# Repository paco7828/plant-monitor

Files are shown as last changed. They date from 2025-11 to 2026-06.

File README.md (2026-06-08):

# Plant Monitor

An ESP32-based smart plant monitoring system with automatic watering, Home Assistant integration via MQTT, and deep sleep power management. Consists of two independent units: the **Plant Monitor** (sensor node) and the **Watering Station** (pump actuator).

---

## System Overview

```
[Plant Monitor ESP32]  --MQTT-->  [MQTT Broker]  --MQTT-->  [Watering Station ESP32]
        |                              |
   Reads sensors                Home Assistant
   Triggers watering cmd         Dashboard / Automations
```

The plant monitor reads sensors and publishes data. When soil moisture drops below the threshold it sends a watering command over MQTT. The watering station subscribes to that command and activates the pump. Both units connect independently to the same WiFi network and MQTT broker.

---

## Hardware

### Plant Monitor

| Component | GPIO |
|---|---|
| Soil moisture sensor (analog) | 0 |
| DS18B20 temperature sensor (OneWire) | 1 |
| LDR light sensor (analog) | 2 |
| Buzzer | 3 |

- ESP32 with deep sleep support
- DS18B20 requires a 4.7k pull-up resistor on the data line

### Watering Station

| Component | GPIO |
|---|---|
| Pump relay / MOSFET | 0 |
| Manual trigger button | 1 |

- Separate ESP32 unit
- Button is active LOW (internal pull-up enabled)
- Manual button press activates the pump for the configured duration regardless of MQTT

---

## Features

### Plant Monitor

**Sensors**
- Soil moisture (analog ADC)
- Ambient temperature via DS18B20 (Dallas OneWire)
- Light presence detection (LDR with configurable threshold)

**Power Management**
- Deep sleep during dark periods (night), waking every 30 minutes to check and publish sensor data
- Stays awake during daylight and publishes every 60 seconds
- RTC memory (`RTC_DATA_ATTR`) persists boot count, sleep time accumulation, last watering time, and last low-moisture beep time across sleep cycles

**Automation**
- Automatic watering triggered when moisture falls below threshold (`MOISTURE_THRESHOLD = 2900`)
- 5-minute cooldown between watering cycles, tracked across deep sleep via RTC memory
- Low moisture buzzer alert every 5 minutes when soil is dry, also tracked across sleep

**Configuration Portal**
- On cold boot: opens WiFi AP (`Smart-Pot`, no password) for 3 minutes
- Captive portal at `192.168.4.1` for entering WiFi SSID/password and MQTT broker settings
- Settings persisted to NVS (`Preferences`)
- On subsequent wakeups from sleep: connects directly using saved credentials

### Watering Station

- Subscribes to `smartpot/water_command`; activates pump for 5 seconds on receiving `"1"`
- Manual button override: activates pump for 5 seconds regardless of MQTT state
- Same captive portal setup flow as the plant monitor for WiFi + MQTT configuration
- WiFi state machine with automatic retry every 15 seconds on connection failure

---

## MQTT Topics

| Topic | Direction | Description |
|---|---|---|
| `smartpot/temperature` | Publish | Temperature in degrees C (string, 2 decimal places) |
| `smartpot/soil_moisture` | Publish | Raw ADC value from moisture sensor |
| `smartpot/sunlight_presence` | Publish | `1` = light, `0` = dark |
| `smartpot/last_watering_time` | Publish (retained) | ISO timestamp of last watering event |
| `smartpot/water_command` | Publish / Subscribe | Plant monitor sends `"1"` to trigger watering |

---

## WiFi / MQTT Configuration

Both units use the same captive portal flow:

1. Power on (cold boot)
2. Connect to the AP (`Smart-Pot` or `Watering-station`)
3. Browser opens the configuration page automatically (captive portal) or navigate to `192.168.4.1`
4. Fill in WiFi credentials and MQTT broker details
5. Submit - the unit connects and begins operation

Configuration is saved to NVS and survives reboot and deep sleep.

---

## Deep Sleep Behavior (Plant Monitor)

| Condition | Behavior |
|---|---|
| Cold boot | AP mode for configuration, then normal operation |
| Dark (LDR below threshold) | Sleep 30 minutes, wake, send data, sleep again |
| Light (LDR above threshold) | Stay awake, send data every 60 seconds |
| MQTT connected + data sent + 15 s minimum awake | Eligible to sleep (if dark) |

Timers that must survive sleep are accumulated in `rtcData.totalSleepTime` so that intervals like watering cooldown and beep suppression work correctly across wakeup cycles.

---

## Thresholds and Timing

### Plant Monitor

| Parameter | Value |
|---|---|
| Moisture threshold (dry) | 2900 (ADC raw) |
| Sunlight threshold | 1500 (ADC raw) |
| Watering cooldown | 5 minutes |
| Low moisture beep interval | 5 minutes |
| Day publish interval | 60 seconds |
| Night sleep interval | 30 minutes |
| AP timeout (cold boot) | 3 minutes |
| WiFi retry interval | 15 seconds |

### Watering Station

| Parameter | Value |
|---|---|
| Pump on duration | 5 seconds |
| AP timeout | 2 minutes |
| WiFi retry interval | 15 seconds |
| Status log interval | 10 seconds |

---

## Home Assistant Integration

Add the following to `configuration.yaml` to expose all entities:

```yaml
mqtt:
  sensor:
    - name: "Smart Pot Temperature"
      state_topic: "smartpot/temperature"
      unit_of_measurement: "C"
      device_class: temperature

    - name: "Smart Pot Soil Moisture"
      state_topic: "smartpot/soil_moisture"

    - name: "Smart Pot Last Watering"
      state_topic: "smartpot/last_watering_time"

  binary_sensor:
    - name: "Smart Pot Sunlight"
      state_topic: "smartpot/sunlight_presence"
      payload_on: "1"
      payload_off: "0"
      device_class: light
```

Restart Home Assistant after editing `configuration.yaml`.

---

## Dependencies

### Plant Monitor

- `OneWire`
- `DallasTemperature`
- `PubSubClient`
- `WiFi`, `WebServer`, `DNSServer`, `Preferences`, `esp_sleep` (built-in ESP32 Arduino)

### Watering Station

- `PubSubClient`
- `WiFi`, `WebServer`, `DNSServer`, `Preferences` (built-in ESP32 Arduino)

---

## Notes

- Both units use `configTime(3600, 3600, "pool.ntp.org")` for NTP time, providing CET offset with DST — adjust the second argument to `0` outside DST periods or use a proper POSIX timezone string for automatic DST handling
- The DS18B20 returns `DEVICE_DISCONNECTED_C` on failure; this is checked before publishing to avoid sending garbage temperature values
- Watering station button is debounced implicitly by the `pumpActive` flag preventing re-trigger while the pump is running

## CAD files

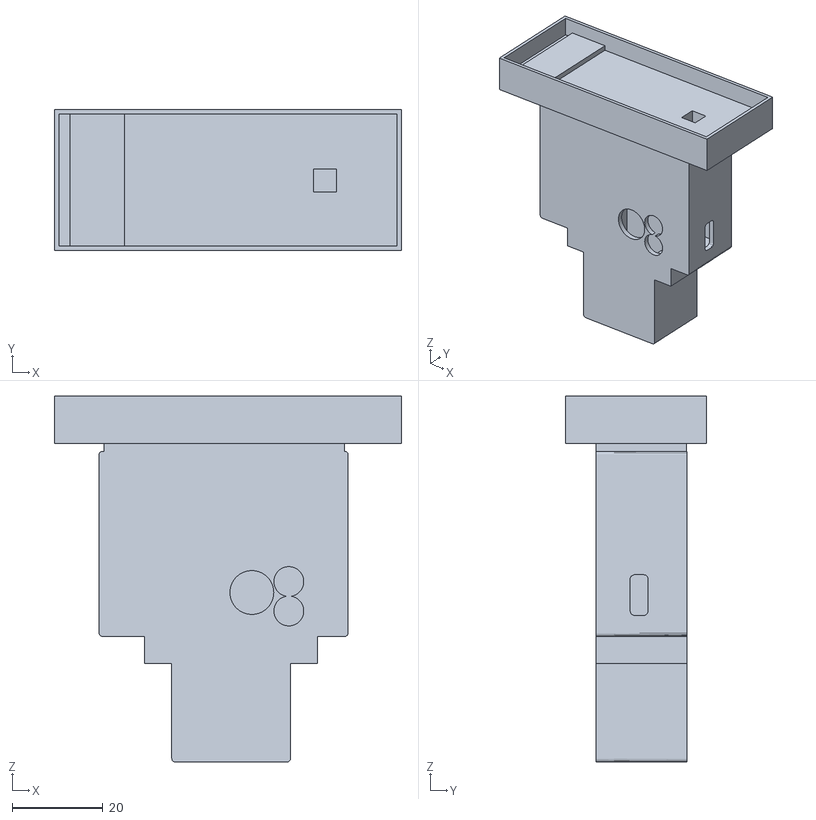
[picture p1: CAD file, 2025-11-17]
v4/Plant-monitor.stl
76.5 x 31.0 x 80.6

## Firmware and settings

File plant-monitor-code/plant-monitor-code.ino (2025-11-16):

#include "config.h"
#include "wifi-handler.h"
#include <OneWire.h>
#include <DallasTemperature.h>
#include <esp_sleep.h>

// Instances
OneWire oneWire(DS_TEMP_PIN);
DallasTemperature temperatureSensor(&oneWire);
WifiHandler wifiHandler;

// Function prototypes
void handleSensorOperations(unsigned long currentMillis);
void handleBuzzerAlerts(unsigned long currentMillis);
void handleAutomation(unsigned long currentMillis);
void handleAPMode(unsigned long currentMillis);
void handleWiFiStateMachine(unsigned long currentMillis);
void goToDeepSleep();
bool areAllTasksCompleted();

void setup() {
  Serial.begin(115200);

  // Pin modes
  pinMode(LDR_PIN, INPUT);
  pinMode(MOISTURE_PIN, INPUT);
  pinMode(BUZZER_PIN, OUTPUT);

  // Check if this is a cold boot
  esp_sleep_wakeup_cause_t wakeup_reason = esp_sleep_get_wakeup_cause();
  isColdBoot = (wakeup_reason == ESP_SLEEP_WAKEUP_UNDEFINED);

  // Play startup sound only on cold boot
  if (isColdBoot) {
    Serial.println("Cold boot detected");
    for (int i = 0; i < 3; i++) {
      tone(BUZZER_PIN, MELODY[i], DURATIONS[i]);
      delay(DELAYS[i]);
    }
  } else {
    Serial.println("Waking from deep sleep");
  }

  temperatureSensor.begin();

  // Initialize or update RTC data
  if (!rtcData.isInitialized) {
    rtcData = { true, 0, 0, 0, 0 };  // Aggregate initialization
  } else {
    rtcData.bootCount++;
    if (rtcData.bootCount > 1) {
      rtcData.totalSleepTime += (DARK_SEND_INTERVAL / 1000);
    }
  }

  // Initialize state variables
  wakeupTime = millis();
  tasksCompleted = false;
  justWokeUp = true;

  // Load configuration
  bool hasCredentials = wifiHandler.loadWiFiCredentials();
  wifiHandler.loadMQTTConfig();

  // Determine initial WiFi state based on boot type and credentials
  if (isColdBoot) {
    // Cold boot - start AP mode first
    Serial.println("Cold boot: Starting Access Point for configuration...");
    wifiHandler.startAccessPoint();
    currentWiFiState = WIFI_SETUP_MODE;
  } else if (hasCredentials) {
    // On wake from sleep with credentials, connect directly
    Serial.println("Wake from sleep: Attempting direct WiFi connection...");
    WiFi.mode(WIFI_STA);
    currentWiFiState = WIFI_CONNECTING;
  } else {
    // Wake from sleep without credentials - start AP
    Serial.println("Wake from sleep: No credentials, starting AP...");
    wifiHandler.startAccessPoint();
    currentWiFiState = WIFI_SETUP_MODE;
  }
}

void loop() {
  unsigned long currentMillis = millis();

  // Handle AP mode if active
  if (wifiHandler.isApModeActive()) {
    handleAPMode(currentMillis);
  }

  // State-independent operations
  isWatering = false;
  handleBuzzerAlerts(currentMillis);

  // WiFi state machine
  handleWiFiStateMachine(currentMillis);

  // Check for deep sleep conditions
  if (!wifiHandler.isApModeActive() && areAllTasksCompleted()) {
    goToDeepSleep();
  }

  delay(100);
}

void handleAPMode(unsigned long currentMillis) {
  wifiHandler.dnsServer.processNextRequest();
  wifiHandler.server.handleClient();

  // Check for AP timeout (only on cold boot)
  if (isColdBoot && (currentMillis - wifiHandler.getApStartTime() >= AP_TIMEOUT)) {
    wifiHandler.stopAccessPoint();
    Serial.println("AP timeout reached on cold boot, stopping AP");

    // Attempt WiFi connection if credentials exist
    if (wifiHandler.loadWiFiCredentials()) {
      WiFi.mode(WIFI_STA);
      currentWiFiState = WIFI_CONNECTING;
      Serial.println("Credentials available, attempting WiFi connection...");
    } else {
      currentWiFiState = WIFI_FAILED;
      Serial.println("No credentials available, operations limited until configured");
    }

    // Clear cold boot flag after first AP timeout
    isColdBoot = false;
  }

  // Handle new credentials saved during AP mode
  if (wifiHandler.areCredentialsSaved()) {
    wifiHandler.setCredentialsSaved(false);
    Serial.println("New credentials saved, stopping AP and attempting connection...");

    // Small delay to allow the HTTP response to be sent
    delay(100);

    wifiHandler.stopAccessPoint();
    delay(1000);
    WiFi.mode(WIFI_STA);
    currentWiFiState = WIFI_CONNECTING;
    isColdBoot = false;  // Clear cold boot flag after successful config
  }
}

void handleWiFiStateMachine(unsigned long currentMillis) {
  switch (currentWiFiState) {
    case WIFI_SETUP_MODE:
      // Waiting in AP mode - nothing to do
      break;

    case WIFI_CONNECTING:
      if (wifiHandler.connectWiFi()) {
        currentWiFiState = WIFI_CONNECTED;
        Serial.println("WiFi connected successfully!");
      } else {
        currentWiFiState = WIFI_FAILED;
        lastWiFiAttempt = currentMillis;
        Serial.println("WiFi connection failed");
      }
      break;

    case WIFI_CONNECTED:
      // Check if WiFi connection is still alive
      if (WiFi.status() != WL_CONNECTED) {
        currentWiFiState = WIFI_FAILED;
        lastWiFiAttempt = currentMillis;
        Serial.println("WiFi connection lost");
        break;
      }

      // Ensure MQTT connection
      if (!wifiHandler.client.connected()) {
        Serial.println("Connecting to MQTT...");
        wifiHandler.reconnectMQTT();
      }

      // Process MQTT and sensor operations if connected
      if (wifiHandler.client.connected()) {
        wifiHandler.client.loop();
        handleSensorOperations(currentMillis);
        handleAutomation(currentMillis);
      }
      break;

    case WIFI_FAILED:
      // Retry WiFi connection after interval
      if (currentMillis - lastWiFiAttempt >= WIFI_RETRY_INTERVAL) {
        currentWiFiState = WIFI_CONNECTING;
        Serial.println("Retrying WiFi connection...");
      }
      break;
  }
}

void handleSensorOperations(unsigned long currentMillis) {
  ldrValue = analogRead(LDR_PIN);
  isDark = ldrValue <= SUNLIGHT_THRESHOLD;

  bool shouldSendData = justWokeUp || (!isDark && (currentMillis - lastDataSendTime >= LIGHT_SEND_INTERVAL));

  if (shouldSendData) {
    lastDataSendTime = currentMillis;
    justWokeUp = false;

    // Read sensors
    temperatureSensor.requestTemperatures();
    temperature = temperatureSensor.getTempCByIndex(0);
    moisture = analogRead(MOISTURE_PIN);

    char dataBuffer[10];

    // Send temperature if valid
    if (temperature != DEVICE_DISCONNECTED_C && temperature > -55 && temperature < 125) {
      dtostrf(temperature, 1, 2, dataBuffer);
      wifiHandler.sendTemperature(dataBuffer);
    }

    // Send moisture
    itoa(moisture, dataBuffer, 10);
    wifiHandler.sendMoisture(dataBuffer);

    // Send sunlight presence
    dataBuffer[0] = isDark ? '0' : '1';
    dataBuffer[1] = '\0';
    wifiHandler.sendSunlightPresence(dataBuffer);

    delay(1000);
  }
}

bool areAllTasksCompleted() {
  unsigned long currentMillis = millis();

  // Minimum awake time requirement
  if (currentMillis - wakeupTime < 15000) {
    return false;
  }

  // Must be dark, data sent after wakeup, and MQTT connected
  if (!isDark || lastDataSendTime <= wakeupTime || !wifiHandler.client.connected()) {
    return false;
  }

  // Track MQTT connection time for watering opportunity
  static unsigned long mqttConnectedTime = 0;

  if (mqttConnectedTime == 0) {
    mqttConnectedTime = currentMillis;
  }

  // Give at least 10 seconds after MQTT connection for watering decision
  if (currentMillis - mqttConnectedTime < 10000) {
    return false;
  }

  return true;
}

void handleBuzzerAlerts(unsigned long currentMillis) {
  // Periodic moisture reading
  if (currentMillis - lastMoistureReading >= 5000) {
    moisture = analogRead(MOISTURE_PIN);
    lastMoistureReading = currentMillis;
  }

  // Calculate time since last beep including sleep time
  unsigned long timeSinceLastBeep = rtcData.totalSleepTime + currentMillis - rtcData.lastLowMoistureBeep;

  // Trigger low moisture beep if needed
  if (moisture < MOISTURE_THRESHOLD && timeSinceLastBeep >= LOW_MOISTURE_BEEP_INTERVAL) {
    tone(BUZZER_PIN, LOW_MOISTURE_HZ, 200);
    rtcData.lastLowMoistureBeep = rtcData.totalSleepTime + currentMillis;
    Serial.println("Low moisture beep triggered");
  }
}

void handleAutomation(unsigned long currentMillis) {
  // Only operate when MQTT is connected
  if (!wifiHandler.client.connected()) {
    return;
  }

  // Periodic moisture check and watering decision
  static unsigned long lastMoistureCheck = 0;

  if (currentMillis - lastMoistureCheck >= 2000) {
    lastMoistureCheck = currentMillis;
    moisture = analogRead(MOISTURE_PIN);
    lastMoistureReading = currentMillis;

    Serial.print("Automation - Moisture: ");
    Serial.print(moisture);
    Serial.print(" | Threshold: ");
    Serial.print(MOISTURE_THRESHOLD);
    Serial.print(" | Dry: ");
    Serial.println(moisture < MOISTURE_THRESHOLD ? "YES" : "NO");

    // Check if watering is needed
    if (moisture < MOISTURE_THRESHOLD) {
      unsigned long timeSinceLastWatering = rtcData.totalSleepTime + millis() - rtcData.lastWateringTime;

      if (timeSinceLastWatering >= WATERING_COOLDOWN) {
        // Trigger watering sequence
        wifiHandler.sendWaterCommand();

        String timestamp = wifiHandler.getCurrentTimestamp();
        wifiHandler.sendLastWateringTime(timestamp.c_str());

        Serial.print("Watering triggered at: ");
        Serial.println(timestamp);

        wateringStartTime = millis();
        rtcData.lastWateringTime = rtcData.totalSleepTime + millis();

        // Reset the low moisture beep timer when watering occurs
        rtcData.lastLowMoistureBeep = rtcData.totalSleepTime + millis();
        Serial.println("Low moisture beep timer reset after watering");

        delay(500);  // Ensure MQTT messages are sent
      } else {
        unsigned long cooldownRemaining = (WATERING_COOLDOWN - timeSinceLastWatering) / 1000;
        Serial.print("Soil is dry but watering is in cooldown. Next watering in: ");
        Serial.print(cooldownRemaining);
        Serial.println("s");
      }
    }
  }
}

void goToDeepSleep() {
  Serial.println("Going to deep sleep...");

  isWatering = false;
  esp_sleep_enable_timer_wakeup(DARK_SEND_INTERVAL);

  WiFi.disconnect();
  WiFi.mode(WIFI_OFF);

  delay(100);
  esp_deep_sleep_start();
}

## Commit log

2025-11-16 Renamed smart-flower-pot to plant-monitor.
2025-11-17 Added shell-v1 for plant-monitor v4.
    [Plant-monitor.stl]
